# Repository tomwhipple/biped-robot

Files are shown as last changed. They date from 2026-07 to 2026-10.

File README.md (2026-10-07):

# Biped

A ~46 cm (to the deck; 56 cm to the top of the head) 3D-printed **bipedal
robot**: 17 serial-bus servos — six per leg, a neck, and two 2-DOF arms that
push it back up after a fall — an ESP32 running the 50 Hz control loop, and a
Raspberry Pi with a head camera. It is designed to walk by lifting a foot
clear of the ground: a static single-foot stance exists with 30 mm of margin,
and the first walk is an open-loop gait validated in simulation against the
measured actuation chain; a reinforcement-learning policy comes after the
body has proven its margins on the floor.

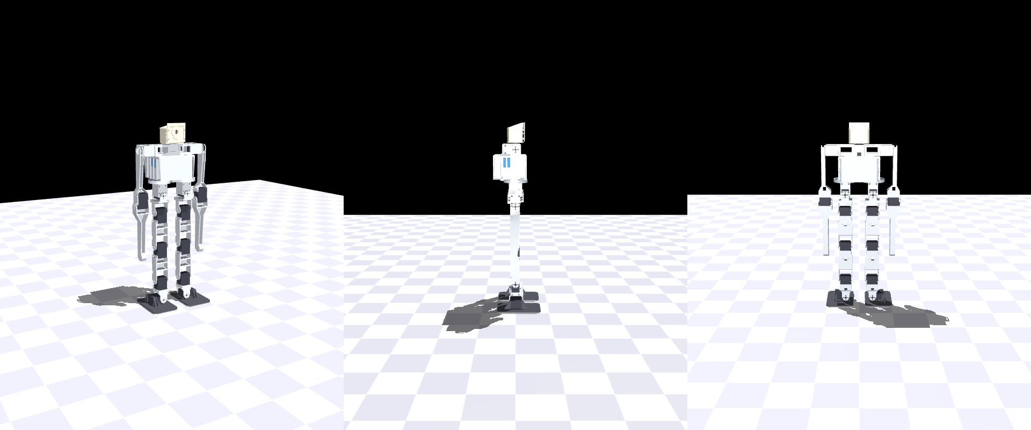
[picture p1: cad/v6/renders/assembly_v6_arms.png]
The robot as drawn: front 3/4, side, front


**Status:** designed, not yet built. The CAD is complete and passes its
swept-ROM interference gate; the design passes simulation Gates A–D. The next
step is one bench measurement on one servo — whether raising the STS3215's
position-loop gain gives the roll-joint stiffness the walk needs (issue #73) —
which gates the servo purchase and the first print. The software stack
(firmware, command link, training, software-in-the-loop) runs on hardware today
on a 10-joint prototype and is being ported to the 17-joint robot.
Where everything stands: [DESIGN.md](DESIGN.md) §12–13 and the GitHub issues.

*Loosely inspired by the [Bimo Project](https://github.com/mekion/the-bimo-project);
an independent design built from servo datasheet dimensions, not reverse-engineered
parts.*

## Try it

Everything below runs on a laptop with no robot and no GPU.

```bash
python -m venv .venv && source .venv/bin/activate    # direnv does this via .envrc
pip install -r requirements.txt

# look at the robot: drag its joints under gravity, push it over (native Qt window)
python sim/joint_puppet.py                 # standing; --pose supine | prone
python -m mujoco.viewer --mjcf=sim/bimo_biped_v6ar.xml

# the design gates, on the robot's plant
MUJOCO_GL=cgl python sim/static_gait.py --render sim/renders/walk.mp4   # the open-loop walk
python sim/gate_no3250.py walk             # the walk across the gate cases

# regenerate the printable parts from the parametric source, then gate them
ARMS=1 python cad/v6/parts_v6.py           # STLs + STEPs + rollup, with the arms
sh cad/run_checks.sh                       # swept-ROM interference, must PASS

# the test gates (also run by the pre-push hook)
python -m pytest tests/ -q                 # ~4 min: physics parity, protocol, ROM, referee, design gates
make -C firmware/host check                # the firmware's pure modules under ASan/UBSan + the consoles
```

The console drives a simulated robot over the real command protocol, and
`--host <robot-ip>` drives a real one:

```bash
brew install glfw && make -C firmware/host deps gui
firmware/host/build/bimo_gui --host 127.0.0.1
#   SIM: pick a run, Start; [a] arm, arrows to walk, PgUp/PgDn to turn
```

**Trained policies are not in the repo.** They are local artifacts under
`sim/runs/` (gitignored); [docs/training.md](docs/training.md) walks the pipeline
from the physics model to the weights compiled into the firmware. Training
wants an NVIDIA GPU; the referee, distillation and export run on a laptop.

## Where to read next

| | |
|---|---|
| [DESIGN.md](DESIGN.md) | **the design**: requirements, kinematics, servos, body, get-up, validation, open decisions, build sequence |
| [cad/README.md](cad/README.md) · [cad/PRINT_LIST.md](cad/PRINT_LIST.md) | the parametric CAD, and what to print and how |
| [docs/bom.md](docs/bom.md) · [docs/assembly.md](docs/assembly.md) | what to buy, and how to put it together |
| [docs/wiring.md](docs/wiring.md) · [docs/servo-map.md](docs/servo-map.md) · [docs/bringup.md](docs/bringup.md) | power and electrical, servo IDs and calibration, bare board to first arm |
| [firmware/README.md](firmware/README.md) · [docs/firmware-design.md](docs/firmware-design.md) | what runs on the ESP32 |
| [docs/control-channel.md](docs/control-channel.md) | the wireless command protocol and its failsafe |
| [docs/training.md](docs/training.md) · [docs/sil-harness.md](docs/sil-harness.md) | how a policy is trained, refereed and deployed |
| [AGENTS.md](AGENTS.md) | working practices: gates, branching, generated files, bench safety |
| [docs/design-v6/](docs/design-v6/README.md) | dated design records and the evidence behind DESIGN.md's numbers |
| [docs/archive/](docs/archive/README.md) | the project's history: the prototype, lessons learned, earlier studies |

## What's in here

```
cad/v6/     the robot's parametric CAD (build123d); cad/v6/dimensions_v6.py is the source of truth
cad/        shared CAD builders and checks, and the prototype's parts (its plant still trains)
sim/        the plants, design gates, open-loop gait and get-up; the CPU env (referee); sim/mjx/ (GPU training); sim/sil/
firmware/   the ESP32 target: the 50 Hz control loop, and its host test build
link/       the command channel: wire protocol, consoles, bench probes
tools/      sim <-> firmware exporters, and instruments that measure servos and the IMU
infra/      nightly training on the GPU box, burst compute
docs/       build, electrical, software and design records
```

## Hardware

17 × Feetech STS3215 (12 V) · Waveshare General Driver for Robots (ESP32,
onboard IMU) · Raspberry Pi 4B + Camera Module 3 Wide · 3S 2200–2600 mAh LiPo ·
PETG prints + silicone rubber soles. Full list: [docs/bom.md](docs/bom.md).

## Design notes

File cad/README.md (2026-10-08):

# CAD

The robot's parametric CAD, written in Python with
[build123d](https://build123d.readthedocs.io/). It lives in **`cad/v6/`**.

- **Dimensions:** every dimension comes from `cad/v6/dimensions_v6.py`. That file
  takes every servo-interface number from `cad/dimensions.py`, which is measured
  from the servo vendor's STEP model.
- **Related docs:** the design is [DESIGN.md §5](../DESIGN.md); what to print and
  how is [PRINT_LIST.md](PRINT_LIST.md); assembly is
  [docs/assembly.md](../docs/assembly.md).

```
cad/
├── v6/                     the robot: part modules, assembly, gates (map below)
│   ├── stl/  step/         exported parts and assemblies (generated)
│   └── renders/            part renders, assembly views, fly-in filmstrips
├── dimensions.py           servo ground truth and shared constants
├── parts.py                shared solid helpers; the prototype's part builders
├── check_assembly.py       servo mocks (used by cad/v6); the prototype's interference check
├── check_printability.py   the printability audit engine
├── fasteners.py            screws as solids (prototype); the hip interfaces' screw sets
├── run_checks.sh           the CAD gate
├── slice.py, orca_profile.py        OrcaSlicer CLI wrapper (PRINT_LIST.md, Slicing)
├── render_part.py, render_assembly.py, animate_assembly.py   renders (below)
├── vendor/ST3215.step      the servo's vendor STEP
└── stl/  step/  renders/   the prototype's parts and renders
```

The prototype's part builders in `parts.py`, and its `cad/stl` and `cad/step`,
exist because the 10-joint training plant (`sim/bimo_biped_v5body.xml`) meshes
`cad/stl`.

## `cad/v6` module map

| module | what it is |
|---|---|
| `dimensions_v6.py` | every dimension the robot adds or changes: kinematics, feet, torso, pack, Pi, neck and head, the hip-yaw bearing (`YAW_BRG_*`, a 6810-2RS), arms and girdle. It re-exports `cad/dimensions.py` as `D`, and `SIM_EXPECT` is the set of numbers the plant must share (pinned by `tests/test_v6_design_gates.py`) |
| `parts_v6.py` | exports every printed part to `stl/` and `step/`, with a bed check and the mass rollup `docs/design-v6/parts_v6_rollup.txt` (`--only <names>`, `--no-export` for the rollup alone) |
| `assembly_v6.py` | the articulated robot: one kinematic chain of parts, servo mocks and electronics mocks, posable (`--pose knee=-60,...`). Writes `step/assembly_v6_arms.step` (`assembly_v6.step` with `ARMS=0`) and `renders/assembly_v6_arms.png`. The checker, the fly-in and the step figures read this chain |
| `check_assembly_v6.py` | the CAD gate: every pair of pieces that move relative to each other, at the ROM extremes plus interior samples; the relatively fixed pairs that must keep their distance (`--joint static`); every disc screw's thread engagement (`--joint screws`). Options: `--joint`, `--samples`, `--side` |
| `animate_v6.py` | fly-in along each part's insertion path. Writes `renders/assembly_v6_flyin*.mp4` (gitignored) and a committed `_strip.png` |
| `render_steps_v6.py` | the assembly guide's step figures, `docs/assembly/v6_*.png`: bench order, the incoming part orange along its insertion path |
| `pelvis_v7.py` | the torso, one print: `pelvis_v7(arm_mounts)` with the yaw servos' seats and the bearing housing's five pilot bosses, its `SCREWS()`, a driver-access check and the board slide checks |
| `yaw_bearing_housing.py` | the hip-yaw bearings' outer-race seats for both hips, one print screwed up under the pelvis, and its `SCREWS()` |
| `yaw_carrier_v6.py` | the prototype's carrier with a 5 mm spacer under its horn plate (`YAW_CARRIER_DROP`: the roll servo and its screws sit below the bearing band) and a round hub for the 6810-2RS's inner race (trimmed below to pass the bearing), and its `SCREWS()` |
| `hip_yoke_v6.py` | the hip roll and pitch clevises fused into one print |
| `yoke_pitch_v6.py` | the pitch clevis alone. `hip_yoke_v6` is built from it; it is printed only under `HIP_YOKE_VARIANT=split` |
| `leg_link_v6.py` | thigh and shin (one part): a 110 mm open-front U with an end wall at each end of the open span |
| `ankle_link.py` | grips the ankle-pitch servo and forks onto the ankle-roll servo |
| `foot_v6.py` | `foot_L`/`foot_R` and the soles' outline `sole_tpu_L`/`_R` (cut from 2 mm silicone sheet) |
| `head.py` | `head_shell`, `head_face`, and `head` (the two fused, for checks) |
| `neck_floor.py` | the neck servo's seat: a plate screwed up into the neck tube's bosses, in the deck's battery aperture (#90); its checks and `tube_bosses()` |
| `neck_collar.py` | the `ARMS=0` variant's neck tube (not a print target: its flange pilots miss the deck) |
| `shoulder_girdle_v6.py` | the girdle: both shoulder pods and the neck tube in one print |
| `arm_v6.py` | upper arm and forearm (mirror pairs), the elbow-servo mock, and the elbow ROM check |
| `audit_torso.py` | printability report for `pelvis_v7`, the head parts and `neck_collar` |
| `audit_ankle_foot.py` | printability report for `ankle_link` and `foot_L/R` |
| `audit_leg_link.py` | printability and interface audit for `leg_link_v6` |
| `check_hip_yoke_clearance.py` | clearance A/B between the hip yoke's raw union and the styled part |
| `print_settings.json` | what `cad/slice.py` slices with: the print spec over Flashforge's presets, and each part's print orientation, supports, copies and overrides. Settings saved in a part's project from the OrcaSlicer GUI are written back here ([PRINT_LIST.md](PRINT_LIST.md), Slicing) |

## Shared builders in `cad/`

- **`dimensions.py`** is the single source of servo truth. It holds:
  - the case, the horn and idler discs and their tapped flanges, the screw rows,
    the rib and platform detents, the idler face, the connector trench and the
    countersinks;
  - the walls and fits (`FIT = 0.30`), the filament density and print factor,
    and the bed size.

  Every `cad/v6` module takes these from here and never retypes them.
- **`parts.py`** provides two things:
  - the solid helpers every `cad/v6` module uses: `box`, `cyl_x/y/z`, `teardrop_x/y`,
    `wedge_x/y/z`, `csk_x/y/z`, `bcd_x`;
  - the prototype parts the robot reuses: `yaw_carrier` (inside `yaw_carrier_v6`), `yoke_roll` and `yoke_pitch` (inside `hip_yoke_v6`), and
    `leg_link` (the basis of `leg_link_v6`).

  Its `main()` exports the prototype's parts to `cad/stl` and `cad/step`.
- **`check_assembly.py`** provides `servo_mock()`: the STS3215 in one canonical
  frame, built from the vendor STEP. `servo_mock_x/_y/_z` are rotations of it,
  so the three orientations cannot drift apart. It also has the board mocks.
  The `cad/v6` assembly and part modules use these. Its `main()` is the prototype's
  own interference check, and it holds the disc-screw engagement rule
  ([docs/assembly.md §1](../docs/assembly.md#1-the-joint-the-servo-is-the-axle)).
- **`check_printability.py`** is the audit engine.
  - It rotates each STL into its print orientation and classifies down-facing
    facets as CEILING, LEDGE, ISLAND, BEAM, first-layer CONTACT or thin wall.
  - Parts listed in `SUPPORTED` are expected to need slicer supports, so their
    overhang findings are reported as support needs, not failures.
  - The v6 audits point its `STL` directory and `ORIENT` table at `cad/v6` at
    runtime.
- **`fasteners.py`** models the prototype's screws as solids. The robot's fastener
  counts take the hip interfaces from it:
  - `disc_screws_x` / `disc_screws_y`, for the hip yoke's roll and pitch
    clevises;
  - `yaw_horn_screws` + `yaw_wall_screws`, for the carrier.

## Regenerate

```bash
.venv/bin/python cad/v6/parts_v6.py                      # the robot: every printed part -> cad/v6/stl + cad/v6/step, bed check, rollup
.venv/bin/python cad/v6/parts_v6.py --no-export          # the rollup alone
.venv/bin/python cad/v6/head.py                          # head_shell, head_face (+ the fused head), audits, render
.venv/bin/python cad/v6/assembly_v6.py                   # step/assembly_v6_arms.step + renders/assembly_v6_arms.png
.venv/bin/python cad/v6/assembly_v6.py --pose hip_pitch=-60,knee=90 --step /tmp/posed.step --png /tmp/posed.png
.venv/bin/python cad/v6/animate_v6.py                    # fly-in mp4 (gitignored) + filmstrip
.venv/bin/python cad/v6/render_steps_v6.py               # docs/assembly/v6_*.png
.venv/bin/python cad/v6/<module>.py                      # one part: STL + STEP + its own audits + render
.venv/bin/python sim/build_v6_inertia.py --write         # the plant from the exported STLs (sim/bimo_biped_v6ar.xml)
.venv/bin/python cad/parts.py                            # the prototype's parts -> cad/stl, cad/step (the training plant meshes them)
```

- **Each part module's `__main__`** exports that part and runs its own audits.
- **Renders on the Mac need `MUJOCO_GL=cgl`.** The scripts default it to `egl`
  (Linux), and on macOS they then skip the render.
- **The exports are generated files:** regenerate them, never edit them. See
  [AGENTS.md](../AGENTS.md). The `ARMS=0` pelvis exports as
  `pelvis_v7_armless`, so it never overwrites the robot's `pelvis_v7`.

**Environment flags** (the defaults are the robot to print):

| flag | default | read by | effect |
|---|---|---|---|
| `ARMS` | `1` | `parts_v6.py`, `assembly_v6.py` (and so `check_assembly_v6.py`, `animate_v6.py`, `render_steps_v6.py`) | the girdle, the four arm links, and the pelvis with the ten girdle pilots. `0` is the armless variant: `neck_collar`, no pilots, no arms |
| `HIP_YOKE_VARIANT` | `single` | `parts_v6.py`, `assembly_v6.py` | `split` builds the bolted `yoke_roll` + `yoke_pitch_v6` pair instead of `hip_yoke_v6` |
| `SERVO_PLAN` | `hips` | `parts_v6.py` (`sim/build_v6_inertia.py --servo-plan`) | `hips`: STS3250s at the two hip rolls, STS3215s elsewhere; `B`: 17 × STS3215; `3250`: STS3250s at the six roll and knee joints (masses only; same case) |
| `MUJOCO_GL` | `egl` (set by default) | every render | set `cgl` on macOS |

## The gate

```bash
sh cad/run_checks.sh          # exit 0 = clear; "CHECKS FAILED -- do not print" otherwise
```

It runs four things with `.venv/bin/python`:

1. **`check_assembly_v6.py` on the default build (the robot, with arms).**
   Every relatively-moving pair is posed at its joint's ROM extremes and
   interior samples. The hip-yaw bearing is in the chain as its two races,
   split at SKF's ring shoulders: the turning side must clear the fixed race
   and the bearing housing through the yaw sweep, and the leg must clear both
   races and the housing.
   - Each pair must show zero intersection and at least `SWEEP_BUFFER` of
     clearance. Designed contacts (pads on discs, seats) are checked for
     volume only, by name.
   - The relatively fixed pairs (the neck floor over the pack, off the pelvis
     and the boards) are checked at the standing pose, each against its own
     minimum distance. The bearing's two press fits must overlap by exactly
     their designed interference volume.
   - The hip's bench order (`--joint insert`): each part swept up its
     insertion path into the state the earlier steps left -- yaw servo,
     carrier, roll servo, bearings into the housing, housing and bearings
     onto the hubs. Only the press fits may overlap; one KNOWN pre-existing
     defect (the seated yaw servo against the cell ceiling) is reported, not
     failed.
   - A 7 mm driver's straight path to every carrier and bearing-housing screw
     in the state that screw is driven in (`--joint access`).
   - Every disc screw's thread engagement is checked against its flange.
   - The pair list is printed with the result, because a pair that is not listed
     was never checked.
   - Results are recorded in `docs/design-v6/cad_rom_check.txt`.
2. **The same check with `ARMS=0`** (the armless variant).
3. **`audit_torso.py`**, a printability report on `cad/v6/stl`.
4. **`audit_ankle_foot.py`**, likewise.

The two printability reports do not fail the run: `pelvis_v7` and `ankle_link`
carry ceilings and islands by design, and supports are the slicer's job. Read
their `**` lines against the slice preview.

**What the gate does not cover:**

- **The other printed parts** audit themselves from their module's `__main__`
  (`leg_link_v6`, `hip_yoke_v6`, `shoulder_girdle_v6`, `arm_v6`). Those rewrite
  their STL as they run, so run them when that part changes.
- **Insertion paths:** on a layout change, `animate_v6.py` proves that the parts
  fly in along them.

`run_checks.sh` is not in the pre-push hook. Run it for any CAD change
([AGENTS.md](../AGENTS.md)).

## Viewing in FreeCAD

Open the STEP exports:

- **the robot:** `cad/v6/step/assembly_v6_arms.step` (`assembly_v6.step` is the
  armless variant);
- **each part:** `cad/v6/step/<part>.step`.

A posed robot is `assembly_v6.py --pose ... --step <file>`. Use the CAD, not
the PNGs, to judge a design: the renders are for documentation.

**Optional: the FreeCAD MCP addon** lets an agent drive a running FreeCAD.

- It is installed in FreeCAD's `v1-1/Mod` and registered user-scope with
  `uvx --with 'mcp[cli]<2' freecad-mcp`.
- It needs the FreeCAD GUI running; the addon's RPC listens on port 9875.

## Servo geometry: the ground truth

**The sources:**

- `cad/vendor/ST3215.step`, Waveshare's STEP model;
- the dimensioned drawing and the Feetech datasheet in
  `docs/datasheets/st3215/`.

`cad/dimensions.py` measures from these programmatically; nothing comes from
photos. The STS3235 and STS3250 share this case, horn and disc pattern, so a
servo swap changes no geometry.

| feature | value |
|---|---|
| case | 45.22 × 24.72 mm, 34.7 across the output axis (35 with the boss); output axis 10.11 from the output end |
| discs | metal horn and free-spinning idler, both Ø19.2 with 4 × M3 on Ø14, tapped through a 2.5 mm (horn) and 2.1 mm (idler) flange |
| case holes | M2.5 at rows 8.30 / 29.00 behind the axis (horn face) and 8.30 / 32.75 (idler face), ±10.25 across |
| idler face | the disc and its hub rotate and stand proud; the stator screw bosses sit 1.78 below the cover slab (mounts land on pads); a horn-side rib sits on the cable half |
| **connector trench, on the idler face** | the two bus ports side by side across the width, in a trench 11.75–16.35 mm from the axis toward the cable end, ±10.9 wide, floor 4.78 below the slab (`SV_CONN_*`) |

**Lead openings belong over the connector trench.** The ports are not on the
cable-end face.

## Renders of the prototype plant

These three scripts render the prototype's parts in `cad/stl`. The training
report (`sim/build_report.py`) reads `cad/renders/assembly_mujoco.png` and
`assembly_flyin.gif`.

| script | output |
|---|---|
| `render_part.py <name or path.stl>` | one STL as a strip of views: `cad/renders/<name>.png`. It takes any STL path, so it works on `cad/v6/stl` parts too |
| `render_assembly.py` | `cad/renders/assembly_mujoco.png` |
| `animate_assembly.py` | `cad/renders/assembly_flyin.gif` and `.mov`, both gitignored |

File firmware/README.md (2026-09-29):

# firmware/ — what runs on the ESP32

The robot's control firmware: an ESP-IDF v5.4, C++17 project for the
Waveshare **General Driver for Robots** (ESP32-D0WD-V3). It boots benched
with torque released, arms over the radio or the USB tether, and runs the
50 Hz policy loop on core 1 with the distilled network compiled into flash.

- Design and rationale: [docs/firmware-design.md](../docs/firmware-design.md)
- Wire protocol and failsafe: [docs/control-channel.md](../docs/control-channel.md)
- First power-up and calibration on the robot: [docs/bringup.md](../docs/bringup.md)
- Servo IDs and calibration values: [docs/servo-map.md](../docs/servo-map.md)
- Electrical: [docs/wiring.md](../docs/wiring.md)
- Bench safety rules: [AGENTS.md](../AGENTS.md#bench-safety)

**Two joint sets.** The **bus** is the robot's 17 servos
(`components/obs/include/obs/bus_map.h`, the proposed ID map of
[docs/servo-map.md](../docs/servo-map.md) §2.1): the calibration blob,
`main/mech_envelope.h`, `pose`/`home`, the gain check, the telemetry joint
block and the SIL arrays are all 17 wide. The **policy** is what the compiled
network observes and commands, from the generated `obs_spec.h`: the
prototype's 10 joints (`kNumJoints = 10`,
`kServoId = {10, 5, 6, 7, 8, 9, 1, 2, 3, 4}`, plant
`sim/bimo_biped_v5body.xml`), policy `loco_v41rsi_b_s128r24`. The loop drives
the policy's joints and holds every other fitted servo; the prototype's
calibration marks IDs 11–17 not fitted
([docs/firmware-design.md](../docs/firmware-design.md) §5.8).

## Build and flash

```sh
env -u VIRTUAL_ENV bash                 # export.sh will not run inside a virtualenv
. ~/esp/esp-idf/export.sh
idf.py -C firmware set-target esp32     # once, for a fresh build directory
idf.py -C firmware build
idf.py -C firmware -p /dev/cu.usbserial-XXXX flash monitor
```

- `export.sh` uses the first `python3` on `PATH`, and it must be the Python
  ESP-IDF's `install.sh` was run with. ninja is optional (`brew install
  ninja` for faster incremental builds).
- The partition table is `partitions.csv`: a 3 MB app partition, with `nvs`
  and `phy_init` at the stock offsets so a reflash keeps the calibration. The
  image is 1 012 832 B, 68 % of the app partition free.
- `sdkconfig` is gitignored and `sdkconfig.defaults` only seeds a new one. A
  checkout configured before the partition table changed is refused at
  configure time: delete `firmware/sdkconfig` and build again.
- The board enumerates as a CP2102N (`/dev/cu.usbserial-*`; macOS may need the
  [CP210x driver](https://files.waveshare.com/wiki/common/CP210x_USB_TO_UART.zip)).
  **Only the USB-C port silkscreened `USB` flashes**; the one silkscreened
  `LIDAR` enumerates a port that never syncs.
- **Opening the serial port resets the board**, which eats the first command
  sent after connecting. Drain and verify before any state-writing command.
- The board boots **benched, torque released**. Nothing moves until `run` on
  the tether or an ARM edge over the radio. Any goal-position write enables
  torque on an STS3215, so every bus write is a motion command.

The pre-push hook (`.githooks/pre-push`) also runs the target build; it finds
ESP-IDF through `idf.py` on `PATH` or `$IDF_PATH`.

## On-target bring-up

[docs/bringup.md](../docs/bringup.md) is the procedure, from a bare board to
the first arm: servo IDs, calibration, the IMU's bias, mount and scale taken
on the robot in the standing pose, WiFi and NTP, torque-release drills, then
the policy loop with the robot on a stand before the floor. `stat` reports
the tick timing and fault counters along the way.

## Host tests (the hardware-free gate)

```sh
make -C firmware/host test     # 10 suites under ASan/UBSan, plus libctrl_sil
make -C firmware/host check    # test + the bimo_tui build (+ bimo_gui on macOS)
```

`check` is what the pre-push hook runs, alongside a CMake + `ctest` build of
the same tests (`firmware/host/CMakeLists.txt`; keep it in step with the
Makefile). Everything compiled here is the same source the board runs, built
with `-Wall -Wextra -Werror -Wshadow -Wconversion -Wsign-conversion`; the
hardware-touching files are excluded by construction.

| suite | covers |
|---|---|
| `protocol` | `linkproto` against golden vectors generated from `link/protocol.py`: frames, CRC, watchdog, arm and home latches, bench diagnostic, UART demux |
| `scsbus` | packet codec against the worked examples in Feetech's protocol manual; transactions against a scripted fake port (a missing servo mid-sync-read, a reply from the wrong ID); the guarded gain write (refused with torque on or unreadable, re-locks on failure, never a goal) and the gain check |
| `obs` | the assembler against real `walker_env._obs()` frames, history order, gait clock, action/angle/tick maps, command shaper, the bus map against the policy spec, calibration blob pack/unpack and the v2 → v3 and v1 migrations |
| `policy` | the forward pass against numpy golden vectors; asserts the weights are the deployed run, not a placeholder |
| `battguard` | the pack guard's thresholds, debounce and landing ramp |
| `fusion` | the attitude filter, cross-checked against MuJoCo's `framezaxis` |
| `obsdump` | the observation dump's double buffer and CSV writer; the mirror-mode pose buffer |
| `sil` | `libctrl_sil`'s C ABI end to end: tick round trips, the bus permutation, the held bus slots, `.silw` and calibration parsing on adversarial input |
| `sil_golden` | the firmware against the sim's own numbers in `sim/sil/golden/*.json`. The obs cases always run; the policy cases run only when the golden run's `.silw` is present and are skipped otherwise |
| `client` | the console core in `link/`: intent, frame-length rule, keymap file, MJPEG parser, recorder, the servo-fault ID list |

The Python half of software-in-the-loop is [sim/sil/README.md](../sim/sil/README.md);
`pytest sim/sil` runs in the pre-push hook after `check` (it needs the library
`check` builds), against the deployed run.

Other targets:

```sh
make -C firmware/host sil       # build/libctrl_sil.{dylib,so} only
make -C firmware/host tui       # build/bimo_tui
make -C firmware/host deps gui  # build/bimo_gui (fetches pinned Dear ImGui + stb into third_party/)
make -C firmware/host vectors   # regenerate protocol_vectors.h from link/protocol.py
make -C firmware/host deploy-headers RUN=<run>   # obs_spec.h + weights.h (+ vectors) from one run
```

`obs_spec.h`, `weights.h` and the files in `host/vectors/` are generated
(AGENTS.md lists the generators); never hand-edit them. The two deployed
headers change only together, and only because somebody named the run to
deploy.

## Module map

```
firmware/
  CMakeLists.txt        ESP-IDF project; -Wall -Wextra -Werror, no exceptions/RTTI
  sdkconfig.defaults    240 MHz, dual core, 1 kHz FreeRTOS tick, static allocation,
                        1 s task watchdog, 4 MB flash / no PSRAM, SNTP settings,
                        the custom partition table
  partitions.csv        nvs + phy_init at the stock offsets, a 3 MB app partition
  main/                 everything that touches ESP-IDF
    board.h             the pinout, from the vendor schematic
    app_main.cpp        NVS, UARTs, IMU, calibration restore, torque off, start tasks
    ctrl_task.cpp       core 1, 50 Hz: sense, guard, observe, act (owns the bus when armed)
    link_task.cpp       core 0: UART0 reader (`link`) and the `housekeeping` task
    wifi_link.cpp       core 0: WiFi station, UDP commands in, telemetry beacon out
    imu_sampler.cpp     core 0: 250 Hz IMU read + fusion, tick-averaged gyro
    timesync.cpp        SNTP wall clock for telemetry timestamps
    cli.cpp             the bench CLI
    cal_store.cpp       servo and IMU calibration blobs in NVS, CRC'd
    asbuilt_cal.h       the as-built zero table (reference for blob migration)
    servo_gains.h       expected position-loop P/D per servo ID (the arm gate)
    mech_envelope.h     per-bus-joint mechanical limits for bench moves
    obs_dump.cpp        the observation dump (`obsdump`)
    joint_pose.h        measured pose, core 1 -> the beacon (mirror mode)
    scs_port_idf.cpp    scsbus::Port over UART1 -- the one servo-bus hardware seam
    shared.h            the only cross-core state, and the rules for it
  components/
    scsbus/             Feetech SCS/STS protocol: codec, transactions, registers;
                        the guarded gain write and the gain check (gains.h)
    linkproto/          C++ port of link/protocol.py: frames, Watchdog, latches, UART demux
    obs/                obs assembler, history, gait clock, actuation maps, shaper;
                        bus_map.h (the 17-servo bus); obs_spec.h (generated)
    policy/             static MLP forward pass; weights.h (generated)
    imu/                Imu interface, frame maths, Fusion, QMI8658C driver, StubImu
    battguard/          pack under-voltage guard
  host/                 host build: Makefile + CMakeLists, 10 test suites, the SIL
                        library (sil.h, sil_lib.cpp, sil_net.cpp), vectors/
tools/
  gen_protocol_vectors.py   link/protocol.py -> host/vectors/protocol_vectors.h
  gen_obs_spec.py           run config + MJCF -> obs/obs_spec.h + obs_vectors.h
  gen_policy_weights.py     <run>.silw -> policy/weights.h + policy_vectors.h
```

## The CLI

USB serial at 115200 on the `USB` port. `help` prints the list. Commands that
touch the bus work only while benched (`run` refuses them); commands that
write NVS are bench-only because a flash write stalls the control tick.

| command | does |
|---|---|
| `scan` | ping IDs 0–253; report position, voltage, faults |
| `ping [id]` | no id: every bus servo, against the fitted set |
| `id <old> <new>` | assign a servo ID (EEPROM; one servo on the bus) |
| `pos <id>` | position, speed, load, voltage, temperature, faults |
| `move <id> <ticks> [ms] [steps/s]` | one servo; 2048 = middle, 4096 ticks/rev; clamped to the mechanical envelope |
| `pose <17 ticks> [...]` / `pose <10 ticks> [...]` | 17 targets in servo-ID order (every bus servo), or 10 in policy order (the prototype's tools); unfitted servos ignored; streamed as a smooth minimum-jerk move by default |
| `trace` | dump the per-servo trace recorded during the last `pose` stream |
| `reg <id> <addr> [1\|2]` | read a servo register |
| `gains [id [P D]]` | position-loop P/D (registers 21/22): no id checks every driven servo against `main/servo_gains.h` (the arm gate); `<id>` reads one; `<id> <P> <D>` writes one, only with its torque off (EEPROM unlock, write, lock, read back; no goal) |
| `home [steps/s]` | every joint to its calibrated zero, hip play take-up, readback, torque released |
| `release [id]` / `torque [id]` | torque off / on; no id = broadcast |
| `middle <id>` | latch the current angle as the servo's 2048 (register 40 ← 128), torque off |
| `volt` | pack voltage, read off the servos |
| `batt [reset]` | pack guard state; `reset` clears a latched trip after a pack swap (bench) |
| `cal [show\|zero [j]\|dir j d\|set j z d\|fit j 0\|1\|migrate\|save\|load\|reset]` | per-bus-joint zero, direction and fitted flag in NVS; `j` is a joint name or a servo ID |
| `shape [hz]` | command-shaper pole; 0 = raw targets |
| `obsfreeze [none\|up\|gyro\|imu\|dq\|gain=k]` | pin or scale parts of the policy observation (diagnostic, not persisted) |
| `run` / `bench` | hand the bus to the control loop / take it back; `run` refuses without an NVS calibration or with any servo's gains off the expected table |
| `imu [scan\|raw [n]\|ring [ms]\|avg [on\|off]\|gscale [x y z]\|reinit\|bias\|mount\|forget\|ae]` | IMU status, I²C scan, raw axes, ringing meter, calibration |
| `wifi [<ssid> <psk>\|clear]` | link status and counters; credentials in NVS |
| `ntp` | SNTP sync state and server |
| `stat` | tick timing per phase, overruns, worst tick, IMU sampler, policy |
| `obsdump [on\|off\|once]` | stream the policy observation as CSV (armed only) |

## Known gaps, as they stand

- `vx_est`/`wz_est` are not estimated and go out as 0.
- `battguard` reads pack voltage from servo register 62 (0.1 V); the on-board
  INA219 is not read.
- The velocity observation is servo register 58; whether a finite difference
  fits better is open (reported/differenced slope 0.69 on the bench).
- The IDF task watchdog on `ctrl` reports only; the loop's own overrun check
  (> 40 ms → torque off) is the protection.
- The 17-servo bus is verified on the host only: a 17-servo `pose` on the
  bench, the robot's leg envelope rows and a policy trained on the robot's
  plant (#86) remain (docs/firmware-design.md §8).

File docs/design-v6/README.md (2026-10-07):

# Design records and evidence

The dated records behind the current design, and the raw logs and figures its
numbers come from. [DESIGN.md](../../DESIGN.md) is the current design; these
records say how each part of it was decided and measured, as of their dates.
The directory name matches the CAD's (`cad/v6/`); it is the current design,
not a version among others.

## Records

| record | what it decided or measured |
|---|---|
| [2026-09-13-design-record.md](2026-09-13-design-record.md) | the validation record: requirements, kinematics sweeps, Gates A–D, servo choice, body revisions, fall-recovery studies, and **§14 Plan B** (STS3215 everywhere with raised P). Code comments cite its sections |
| [experiments/plan-b-bench/](../../experiments/plan-b-bench/) | the Plan B bench (#73), in its own folder: `gain_bench.py`, the rig (CAD, STLs, figures) and its dated sessions -- session 1, the bench servo's registers and the unloaded P ladder; gain-write ack loss (#101) |
| [getup-decision-2026-09-17.md](getup-decision-2026-09-17.md) | the get-up decision (two elbowed arms) and **every dead end with its measured reason**, so none is retried |
| [getup-noappendage-2026-09-14.md](getup-noappendage-2026-09-14.md) | the no-appendage get-up search (kip, bear, crow, bridge, skid, bumper): negative, and the hip −90…−100° crouch finding; figures in `figs/` |
| [study-shoulder-arms.md](study-shoulder-arms.md) | the arm study behind that decision: reach threshold, elbow, mount position |
| [shoulder-girdle.md](shoulder-girdle.md) | shoulders into the torso in the hip plane; assembly order; §11 the get-up re-run on the robot as drawn |
| [arms.md](arms.md) | the arm parts in CAD, their ROM and open items |
| [elbow-servo-upper-arm-2026-10-07.md](elbow-servo-upper-arm-2026-10-07.md) | the elbow servo's case moves from the forearm to the upper arm; both arm links take the leg link's open-U section with end walls; before/after on every gate |
| [hip-yoke-single-print.md](hip-yoke-single-print.md) | the hip roll and pitch clevises as one print; hip-flexion relief to −120° |
| [failure_sweep_2026-10-07.md](failure_sweep_2026-10-07.md) | failure modes of the kinematic walk on the robot plant: 434k random walks; roll play, lift height, actuation lag and swing time decide falls and lift |
| [foot_outline_2026-10-07.md](foot_outline_2026-10-07.md) | the printed foot sat 12 mm outboard of the spec; at the spec the feet touch at 2.1° of mutual hip-roll adduction. Gate D margin vs adduction clearance at three sole placements (open, for Tom) |
| [study-yaw-bearing.md](study-yaw-bearing.md) | hip-yaw bearing options A / C / E and their checks; A selected 2026-10-06 (#75) |

Records here describe what was true on their date; where one disagrees with
DESIGN.md, DESIGN.md is current. Evidence logs for options not taken (legs-only
and tail get-ups, short arms, the split hip yoke, the first arm brackets) were
removed from the tree on 2026-09-29 and remain in git history.

## Evidence

Logs (`*.txt`, `*.json`) are the verbatim output of the scripts named in their
headers; figures (`*_strip.png`) are filmstrips of the runs. The ones DESIGN.md
leans on:

| evidence | backs |
|---|---|
| `gateA_geometry_sweep.txt`, `gateB_mixed.txt`, `gateAB_v7.txt` | kinematics and actuator envelope (Gates A, B) |
| `gateCD_sweep*.txt`, `gateD_*.txt` | the open-loop walk across the adversity matrix |
| `no3250_{walk,sweep,envelope,arms_walk,getup}.txt`, `no3250_{walk,arms_walk}_plant17.txt`, `no3250_*_elbow_upper.txt` | Plan B: every gate with STS3215s and raised P; the walk on the regenerated 17-actuator plant; the elbow-servo move against main |
| `getup_search_r6_asdrawn*.txt`, `getup_search_r5_asdrawn*.txt`, `getup_search_shoulder_*.txt`, `getup_search_girdle_*.txt`, `getup_search_hipplane_*.txt`, `getup_search_legroll*.txt` | the get-up on the as-drawn robot, the arm choice, the prone roll |
| `cad_rom_check.txt`, `girdle_check_assembly.txt`, `hip_yoke_check_single.txt`, `yaw_bearing_check*.txt`, `yaw_bearing_options_2026-09-29.txt` | the CAD interference gates; the A / C / E comparison for #75 (A selected) |
| `parts_v6_rollup.txt` | part masses and the print rollup (regenerated by `cad/v6/parts_v6.py`) |
| `deep_flexion_sweep.txt` | knee 130° / hip flexion limits |

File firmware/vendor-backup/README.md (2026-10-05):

# Vendor firmware backup

`waveshare_stock_4MB.bin` is a full 4 MB dump of the Waveshare "Servo Driver
with ESP32" flash **exactly as it shipped**, taken 2026-07-26 before our
firmware was flashed for the first time.

    sha256  5ef7db3e1ea47654016b060016979e3e4b9758780dd5bf3262e1d1ac54f6db0f
    size    4194304 bytes
    chip    ESP32-D0WD-V3 rev 3.1, MAC xx:xx:xx:xx:xx:xx

**The .bin is deliberately not in git** (4 MB binary — see `../.gitignore`).
If it is missing and the board still runs vendor firmware, retake it:

```
. ~/esp/esp-idf/export.sh
esptool.py --port /dev/cu.usbserial-0001 -b 460800 \
    read_flash 0 0x400000 firmware/vendor-backup/waveshare_stock_4MB.bin
```

## Restoring it

```
. ~/esp/esp-idf/export.sh
esptool.py --port /dev/cu.usbserial-0001 -b 460800 \
    write_flash 0 firmware/vendor-backup/waveshare_stock_4MB.bin
```

That puts the stock web UI back at `192.168.4.1` (AP `ESP32_DEV` /
`12345678`), including its ID-setting page.

## Why you would, and mostly would not

Kept as insurance for the first hardware run of our firmware, not because the
vendor image is worth returning to. It is **actively wrong for these servos**:
the board ships the **SC-series** build, which is big-endian, while the ST3215
is ST-series little-endian — so every 16-bit value it exchanges is
byte-swapped. Measured on servo 9: it reported position 772 for an actual
1027, and its "Set Servo Mode" button wrote angle limits of 5120 and 60163
instead of 20 and 1003. Only 8-bit registers (ID, mode, torque) survive the
trip intact.

See [docs/bringup.md](../../docs/bringup.md) for the full measurement.

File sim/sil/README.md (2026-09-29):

# Software-in-the-loop (SIL) harness — usage

The firmware's real control path, driven by the CPU referee plant. The
design contract (ABI, rules, pyramid, findings) is
[docs/sil-harness.md](../../docs/sil-harness.md).

```
walker_env  --calibrated ticks + IMU floats-->  libctrl_sil  --goal ticks-->  walker_env
            (SilSensors)                       (firmware code) (SilTargets)
```

Nothing in `libctrl_sil` knows it is talking to a simulator: the observation
assembler, history ring, gait clock, MLP, command shaper and angle ↔ tick
calibration are the firmware's own sources compiled for the host. This
directory is the translation layer and its tests.

## Build and run

```sh
# 1. export the deployed run (needs sim/runs/<run>/params.pkl + config.json;
#    the run is obs::kRunName in obs_spec.h). --no-golden keeps the committed
#    golden vectors in sim/sil/golden/ as they are.
JAX_PLATFORMS=cpu .venv/bin/python tools/export_policy_weights.py --run <run> --no-golden

# 2. the C side
make -C firmware/host sil          # -> firmware/host/build/libctrl_sil.{dylib,so}
make -C firmware/host test         # pyramid item 1, part of the pre-push gate

# 3. the Python side (also a pre-push gate)
.venv/bin/python -m pytest sim/sil -q                 # everything (seconds)
.venv/bin/python -m pytest sim/sil -q -m "not slow"   # skip the closed-loop scenarios
```

`conftest.py` pins JAX to the CPU. Always pass `--run` to the exporter (its
built-in default is not a run this suite uses). Without `--no-golden` it
rewrites `sim/sil/golden/*.json`, which the firmware host tests consume: do
that when the deployed run changes, in the same commit as
`make -C firmware/host deploy-headers RUN=<run>`.

Knobs (environment):

| var | default | meaning |
|---|---|---|
| `SIL_RUN` | the deployed run: `obs::kRunName`, read from `obs_spec.h` (`harness.DEFAULT_RUN`) | the run whose `sim/runs/<run>/config.json`, `params.pkl` and `weights/<run>.silw` the suite loads |
| `SIL_LIB` | search `firmware/host/build`, then `firmware/host` | explicit library path |
| `SIL_SEEDS` | `8` | closed-loop episodes per scenario; seeds are `100·i + 7`, exactly `eval_precision`'s |
| `SIL_ASSUME_ORDER` | auto-probed | force `joint` or `ascending_id` array order |

`sim/runs/` and the `.silw` blobs are gitignored. Without the run's files the
tests that need them skip, each naming the file it lacks and the command that
makes it; without the library, the library-dependent tests skip. The rest
(the one-run consistency check, the goldens, the boundary, the inverse action
map) always run.

## Current status

`pytest sim/sil` is a hard gate in the pre-push hook. On the deployed run
(`loco_v41rsi_b_s128r24`, plant `bimo_biped_v5body.xml`) it is **35 passed**
in ~15 s, closed loop included; on a clean clone, 16 passed and 19 skipped.
The headers, the goldens and the harness default are the same run, and
`test_goldens_headers_and_harness_agree_on_one_run` keeps them so
([docs/sil-harness.md](../../docs/sil-harness.md#one-run-the-deployed-one)).
The firmware MLP matches brax on the same observation to ~3e-7 (`net_err`).

## Files

| file | what it is |
|---|---|
| `tools/export_policy_weights.py` | `params.pkl` → `.silw` + sidecar (+ golden vectors unless `--no-golden`) |
| `harness.py` | ctypes ABI, calibration maths, boundary conversion, the ABI probe, `SilActAdapter`, the deployed-run default |
| `test_sil.py` | pyramid items 2, 3 and 4, and the one-run check |
| `conftest.py` | CPU-only JAX, the `slow` marker |
| `weights/<run>.silw.json` | committed sidecars; `loco_v41rsi_b_s128r24` is the deployed run's, `loco_v11gait` is `sim/sil_twin.py`'s default |
| `weights/<run>.silw` | the exported blob; gitignored, regenerated by step 1 |
| `golden/policy_vectors.json` | 16 normalised-obs → action pairs (brax, deterministic), the deployed run |
| `golden/obs_vectors.json` | 8 `walker_env` states → `_obs()` frame + `obs::Inputs`, same run |
| `cal/cal_{nominal,perturbed}.json` | the two calibrations `sil_init()` takes |

`sim/sil_twin.py` and `bimo_gui`'s SIM panel can run any run that has both
`sim/runs/<run>/config.json` and `weights/<run>.silw.json`.

## The `.silw` layout as written

Little-endian throughout. `header_bytes = 44 + 4·num_sizes` (64 for a
`147 → 512 → 256 → 128 → 20` net).

```
off  type          n           field
  0  char[4]       4           magic "SILW"
  4  u32           1           version = 1
  8  u32           1           header_bytes  (byte offset of the f32 payload)
 12  u32           1           obs_dim       (147)
 16  u32           1           act_dim       (10)
 20  u32           1           num_layers
 24  u32           1           num_sizes     (num_layers + 1)
 28  char[16]      16          activation, NUL-padded ("swish")
 44  u32           num_sizes   layer_sizes, e.g. [147, 512, 256, 128, 20]
 -- header_bytes --
     f32           obs_dim     norm_mean
     f32           obs_dim     norm_std
     f32           in_0*out_0  W0, row-major (in, out): flax order, no transpose
     f32           out_0       b0
     ...                       W1, b1, ... for every layer
```

For the 147 → 512 → 256 → 128 → 20 net the payload is 242 874 floats.
`--raw` writes the payload with no header (`header_bytes = 0`); the sidecar
is then the only description. The sidecar `<run>.silw.json` carries
`layer_sizes`, `activation`, `obs_dim`, `act_dim`, `normalizer.{mean,std}`,
the source run's plant and observation shape, and a `blob` block
(`header_bytes`, `order`, `n_floats`, `bytes`, `sha256`) so a reader can
cross-check the bytes.

What a consumer must reproduce, all in float32:

```
x      = (obs - mean) / std          brax running_statistics.normalize, no clip
h      = swish(h @ W_i + b_i)        every hidden layer
logits = h @ W_out + b_out           linear, 2 * act_dim wide
action = tanh(logits[:act_dim])      NormalTanhDistribution.mode()
```

## The calibration file

```json
{"num_joints": 10,
 "joints": [{"index": 0, "name": "L_hip_yaw", "bus_id": 10,
             "zero_steps": 2048, "dir": 1}, ...],
 "bus_id": [...], "zero_steps": [...], "dir": [...]}
```

The three flat arrays are joint-indexed mirrors of `joints`; a reader may
use either shape. `bus_id` follows the generated `kServoId`. The library
takes an entry for every servo the policy drives and accepts one for any
servo on the 17-servo bus; the harness's files carry the policy's ten.

The ctypes structs are bus-wide (17 slots, servo-ID order, `sil_abi` 3); the
harness reads the width from `firmware/components/obs/include/obs/bus_map.h`
(`harness.NUM_BUS`) and fills the slots the policy does not drive with 2048.
`cal_nominal.json` is `zero_steps = 2048, dir = +1` (identical to
`obs::Calibration`'s default); `cal_perturbed.json` has random zeros in
2048 ± 350. Neither is the as-built calibration: they describe a robot whose
servos agree with the plant, which makes them clean round-trip fixtures. The
real robot's zeros and directions are in
[docs/servo-map.md](../../docs/servo-map.md) and `firmware/main/asbuilt_cal.h`.

## The referee column (`--sil`)

```sh
cd sim/mjx && JAX_PLATFORMS=cpu ../../.venv/bin/python \
    eval_precision.py --run-name <run> --sil      # -> sim/runs/<run>/scorecard_sil.{md,json}
```

`--sil` builds the library and exports the run's weights (with `--no-golden`)
when they are missing or stale, then scores the run with the firmware stack
in the `act()` slot. `infra/night_collect_local.sh` runs it for every
collected run.

## Notes for whoever touches this next

**The ABI's array order is probed, not assumed.** `SilLib.probe()` ticks
once with a distinguishable tick pattern and reads `SilTargets.obs` back to
determine, in the tick domain (so a non-uniform calibration cannot pass for a
permutation), the sensor array order, the `goal_ticks` order, and whether
`vel_ticks` is two's complement or the servo's sign-magnitude word. It runs
with the shaper off and restores it. A disagreement is a `ProbeFailed` with
both candidate errors in the message; `SIL_ASSUME_ORDER` overrides.

**The gait clocks tick at opposite ends.** `ctrl_task.cpp` advances the clock
*before* assembling the frame; `walker_env.step()` advances it at the *end*.
So the firmware's phase at tick *k* is `(k+1)·ω` and walker_env's is
`p₀ + k·ω`. `pin_gait_clock(env, hz)` sets `p₀ = ω` (and refills the history
ring) to align them; only the per-tick parity tests need it. The closed-loop
scenarios deliberately do not pin.

**The harness takes the IMU from the observation, not from `env.data`.**
`walker_env._obs()` pushes the up-vector through a per-episode mounting
rotation, adds noise and biases the gyro, and redraws that noise on every
call. Reading those channels back out of the observation frame is the only
way to give the SIL loop the same IMU realisation the python policy saw;
reading `sensordata` would bypass the mounting error the harness exists to
exercise.

**Frozen normaliser channels.** `test_normalizer_frozen_channels_are_known`
pins which channels the suite's run never varied; see finding 2 in the design
doc for why a frozen channel the robot does feed is a hazard.

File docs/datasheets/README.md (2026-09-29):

# Datasheets

These are manufacturer documents for the parts in the build. They are mirrored
here so that CAD work and bring-up do not depend on a live listing. The owner's
policy: only source parts that have real manufacturer documentation, meaning
connector graphics and specs. A rendered web snapshot or a self-authored "manual"
does not count.

## Feetech STS3215 (ST-3215-C018): every joint

The files are in [`st3215/`](st3215/). The part to buy is the **12 V class,
ST-3215-C018** (30 kg·cm).

- The 7.4 V STS3215 shares the case but cannot run on 3S.
- Resellers (Waveshare, RCmall, Stemedu …) sell the same Feetech part, so buy by voltage class.

| file | what it is | source |
|---|---|---|
| `ST-3215-C018-datasheet-12V-30kg.pdf` | **The authoritative spec.** Ed. A/0, 2023-07-20, 8 pp. Chinese with English headings. §5 electrical, §6 mechanical, §7 control and protections, §9 outline, §10 performance curves | [feetechrc.com](https://www.feetechrc.com/525603.html) |
| `ST-3215-C018-outline-and-performance.png` | rendered quick-look of the outline and performance pages | rendered locally |
| `ST3215-outline-drawing.pdf` / `.dxf` / `.png` | standalone dimensioned drawing, 3 views plus mounting holes. The title block says "SCS215", the same case family; every dimension matches the C018 outline | Waveshare [ST3215-2D.zip](https://files.waveshare.com/upload/0/08/ST3215-2D.zip) |
| `ST3215-Servo-User-Manual-EN.pdf` | Waveshare's ST3215 user manual. It is mostly about Waveshare's Servo Driver board and its web UI, and has **no register map** | [Waveshare wiki](https://www.waveshare.com/wiki/ST3215_Servo) |
| `STS3215-datasheet-7.4V-19kg-EN-machine-translated.pdf` | The **7.4 V** part, machine-translated. Wrong voltage class. Never read torque or current from it | [Core Electronics](https://core-electronics.com.au/attachments/uploads/sts3215-smart-servo-datasheet-translated.pdf) |
| `../../cad/vendor/ST3215.step` | 3D solid, bounding box 45.22 × 37.8 × 24.72 mm | Waveshare [ST3215-3D.zip](https://files.waveshare.com/upload/5/59/ST3215-3D.zip) |

The C018's key numbers:

- 12 V rated, 4–14 V input range (protection trips outside that range).
- 30 kg·cm stall (2.94 N·m) at 2.7 A.
- 180 mA running with no load; 30 mA idle.
- 0.222 s/60° with no load.
- Backlash ≤ 0.5°; gear ratio 1:345.
- 55 ± 1 g.
- 25T output spline, OD 5.9; M3×6 horn screw.
- 5264-3P connector (1 GND, 2 V+, 3 signal) on a 150 mm lead.
- Bus at 38.4 kbps–1 Mbps; factory default 1 Mbps, ID 1.

The Waveshare wiki gives the supply as 6–12.6 V.

The drawing's dimensions, in mm:

- Case: 45.22 × 24.72; 35 overall across the output axis.
- Horn face to idler-disc face: **37.25**.
- Output axis: 10.11 from the output end, centred across the width.
- Horn and idler discs: Ø19.2, on a Ø14 4 × M3 bolt circle.
- Case bosses: ±10.25 across the width, in rows 8.30 and 29.00 behind the output axis.

`cad/dimensions.py` states the same numbers. The drawing is the receipt for them.

## Waveshare General Driver for Robots: the controller

The files are in [`general-driver/`](general-driver/), which has its own
[index](general-driver/README.md). The set is:

- the schematic;
- the dimension drawing;
- the annotated connector photo;
- the JST XH datasheet;
- the QMI8658C IMU datasheet.

## Not mirrored yet

| document | source | why |
|---|---|---|
| Feetech ST3215 memory table v3.7 (register map, defaults) | [xls](https://files.waveshare.com/upload/2/27/ST3215%20memory%20register%20map-EN.xls), cited in `firmware/components/scsbus/include/scsbus/registers.h` | the register reference behind [servo-map.md §4](../servo-map.md#4-registers) |
| Feetech communication protocol manual | [pdf](https://files.waveshare.com/upload/2/27/Communication_Protocol_User_Manual-EN(191218-0923).pdf) | packet format; the source of the `scsbus` golden packets |

## To download

These parts are in the build, but their manufacturer documents are not in the
repo yet:

| part | manufacturer documents |
|---|---|
| Raspberry Pi 4 Model B | [product brief](https://datasheets.raspberrypi.com/rpi4/raspberry-pi-4-product-brief.pdf), [datasheet](https://datasheets.raspberrypi.com/rpi4/raspberry-pi-4-datasheet.pdf), [mechanical drawing](https://datasheets.raspberrypi.com/rpi4/raspberry-pi-4-mechanical-drawing.pdf) |
| Raspberry Pi Camera Module 3 (Wide) | [product brief](https://datasheets.raspberrypi.com/camera/camera-module-3-product-brief.pdf) |
| Pololu D24V50F5, 5 V / 5 A buck | [product page](https://www.pololu.com/product/2851), with its dimension diagram. The pelvis bosses wait on the hole pattern |
| 3S LiPo pack | the chosen pack's manufacturer spec sheet: dimensions, capacity, C rating, connector |
| 3S protection board | the chosen board's manufacturer datasheet: continuous current, cut-off voltages, balance-lead pinout |

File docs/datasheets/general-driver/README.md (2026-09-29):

# General Driver for Robots: manufacturer documents

These are Waveshare's documents for the robot's controller board, mirrored
verbatim, plus the datasheets for two parts on it. Waveshare publishes **no user
manual** for this board. The connector table, the FAQ and the demo code exist only
on the wiki. Its stable permalink is
<https://www.waveshare.com/w/index.php?title=General_Driver_for_Robots&oldid=103968>,
retrieved 2026-08-03.

| file | what it is | source |
|---|---|---|
| [General_Driver_for_Robots-schematic.pdf](General_Driver_for_Robots-schematic.pdf) | the full schematic, one A3 sheet. It is the authority for every net and GPIO | [files.waveshare.com](https://files.waveshare.com/upload/3/37/General_Driver_for_Robots.pdf) |
| [General_Driver_for_Robots-dimensions.pdf](General_Driver_for_Robots-dimensions.pdf) | dimension drawing: outline **65.01 × 56.01 mm**, holes on a 58 × 49 mm grid (58 along the 65 edge) | Waveshare |
| [General_Driver_for_Robots-connector-diagram.jpg](General_Driver_for_Robots-connector-diagram.jpg) | the official annotated photo, with every connector numbered 1–27, front and back | Waveshare wiki |
| [JST-XH-connector-datasheet.pdf](JST-XH-connector-datasheet.pdf) | JST XH series, the family of the power inlet: 3 A AC/DC per contact at AWG #22, conductors AWG #30–#22 | [jst-mfg.com](https://www.jst-mfg.com/product/pdf/eng/eXH.pdf) |
| [QMI8658C-datasheet.pdf](QMI8658C-datasheet.pdf) | QST QMI8658C 6-axis IMU, the robot's IMU at 0x6B. Rev 0.6, 2021-01-13, stamped "advance information" | QST, via Waveshare |

Where the documents disagree:

- **Dimensions.** The wiki lists the board as "65 x 65mm". The drawing says 65.01 × 56.01. Trust the drawing.
- **Input voltage.**
  - The wiki says "DC 7-13V" and that the XH port "directly powers the serial bus servo and motor".
  - The rev 1.2 silkscreen says "DC 9-12.6V", which would exclude 2S.
  - This is unresolved. A 3S pack is inside both ranges.
- **Bus current.** The wiki FAQ limits bus-servo current to "5A for long-term operation", which is "up to 5 servos (ensuring that these 5 servos are not stalled simultaneously)". The robot runs 17. That is open; see [wiring.md](../../wiring.md#current-the-open-constraint).
- **QMI8658C output registers.** The datasheet's Motion-on-Demand text cites output registers 0x25–0x3D, while its dQ/dV register map puts them at 0x49–0x56. Trust the silicon, not the sheet (`imu ae` on the CLI).

The connector → net → GPIO map derived from the schematic is in
[sensor-expansion.md §1](../../sensor-expansion.md#1-the-boards-connectors). What the
INA219 measures is in [wiring.md](../../wiring.md#what-the-ina219-measures).

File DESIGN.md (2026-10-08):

# Design

The current design of the robot: what it is, why each choice was made, what
has been validated and how, and what is still open. Dated records and the
evidence behind these numbers are in [docs/design-v6/](docs/design-v6/README.md);
the project's earlier history is in [docs/archive/](docs/archive/README.md).

**State:** the CAD is complete and passes its swept-ROM interference gate
(armless and with arms); the design passes simulation Gates A–D under the
servo plan below. Nothing has been printed or bought. The first step is a bench
measurement on one servo (issue #73), which gates the servo purchase.

The robot as drawn (front 3/4, side, front)

## 1. Goal and requirements

A small 3D-printed biped that **walks by lifting one foot completely off the
ground**, gets itself up after a fall, and carries an onboard computer and a
head camera for navigation. Walking and get-up come from the body and an
open-loop gait first; a learned policy comes last, once the hardware has shown
its margins.

Each requirement traces to a measurement on the earlier 10-joint prototype
(see [lessons learned](docs/archive/2026-09-13-lessons-learned-walking.md)):

| | requirement | how the design meets it |
|---|---|---|
| R1 | A **static single-foot stance** must exist, with margin | ankle roll: a 6th joint per leg (Gate A: 30 mm CoM margin on one foot) |
| R2 | Margins are measured on the body **before any policy** | Gates A–D in simulation, then the same open-loop script on the bench; the policy (Gate E) is last |
| R3 | The **roll chains must be stiff** | every roll joint double-supported (horn + idler); servo stiffness is the one gated assumption (§4) |
| R4 | **Speed and torque margin** under load: ≥ 2× speed, ≥ 1.5× torque at 11.1 V | met at the design cadence (§8) |
| R5 | Contact realism made adversarial | every gate runs μ 0.3–1.0, full self-collision, free play on the rolls, and the deployed actuation chain |
| R6 | An onboard computer and camera | Raspberry Pi 4B in the torso, Camera Module 3 Wide in a head on a neck servo |
| R7 | Keep what is proven | hip yaw (decisive for turning in place), the "servo is the axle" leg link, one-print torso, the 50 Hz ESP32 control loop, the General Driver board, a 3S pack |
| R8 | Size may grow to ~45 cm and a bigger pack | deck top 465 mm, head top 560 mm |

## 2. The robot at a glance

| | |
|---|---|
| joints | **17**: per leg hip yaw, hip roll, hip pitch, knee, ankle pitch, ankle roll (12); neck yaw (1); per arm shoulder pitch, elbow (4) |
| servos | 15 × Feetech STS3215 (12 V, ST-3215-C018), with a raised position-loop gain on the ankle rolls and knees, and 2 × STS3250 at the hip rolls (§4) |
| height | deck top 465 mm, camera 534 mm, head top 560 mm |
| mass | ≈ 2.28 kg as drawn (§7) |
| controller | Waveshare General Driver for Robots (ESP32, onboard QMI8658C IMU), 1 Mbaud half-duplex servo bus |
| compute | Raspberry Pi 4B (vision, navigation), talking to the ESP32 |
| camera | Raspberry Pi Camera Module 3 Wide (102° HFOV) in the head, ±90° neck yaw |
| power | 3S LiPo 2200–2600 mAh (≤ 105 × 36 × 26 mm, ~170 g), protection board, inline fuse, 5 V / 5 A buck for the Pi |
| structure | PETG prints, 2 mm silicone rubber soles; M2.5 flat-head self-tappers into printed pilots, M3 screws on the servo horns and idler discs |

## 3. Kinematics

Frames: +X forward, +Y left, +Z up. Leg chain from the pelvis down: yaw → roll →
pitch → knee → ankle pitch → ankle roll.

| joint | axis | range as drawn | servo placement |
|---|---|---|---|
| hip yaw | Z | ±45° | in a cell under the pelvis's battery layer, horn down; the yaw carrier (the whole leg) bolts to the horn |
| hip roll | X | ±55° swept (sim: 30° adduction, 45° abduction) | in the yaw carrier's bay, output forward |
| hip pitch | Y | −120° … +90° | at the thigh top, 50 mm below the roll axis, gripped by the leg link |
| knee | Y | 0 … 130° flexion | at the shin top; relief cuts on the leg link allow the deep flexion the get-up needs |
| ankle pitch | Y | ±40° | hangs in the ankle link's grip channel |
| ankle roll | X | ±25° | lies across the foot, output axis fore-aft; the ankle link forks onto its horn (front) and idler (rear) |
| neck yaw | Z | ±90° | stands on the deck, horn up; the head bolts to the horn |
| shoulder pitch | Y | −90° … +200° (0 = hanging, 90 = straight back, 180 = up along the torso) | lies fore-aft inside the shoulder girdle, horn outboard |
| elbow | Y | −100° … +10° | in the upper arm's grip channel, case running up the arm; the forearm forks round it on both discs |

**Axis stack** above the sole: ankle roll 18.4 → ankle pitch 76.4 → knee 186.4 →
hip pitch 296.4 → hip roll 346.4 → hip yaw 391.5 → deck top 465.3 → shoulder
481.6 mm. Thigh and shin are 110 mm each (the same printed part); ankle pitch to
roll 58 mm; hip roll to hip yaw 45.1 mm (the yaw carrier, §5.2).

**Why these numbers** (Gate A/D sweeps, `docs/design-v6/gateA_geometry_sweep.txt`):

- **Hip separation 84 mm.** The one-foot CoM margin is half the foot width
  whatever the hips do, so the foot is the margin budget and the hips set roll
  torque: narrower is stiffer (3.4× torque margin at 70 mm, 1.0× — stalled — at
  96 mm). At 72 mm the swing foot, which sags 12–15 mm inward while it hangs,
  lands on the stance foot. 84 mm leaves 37 mm between the soles and room for
  the pack between the yaw servos.
- **Legs 110 + 110 mm.** Longer levers lower the joint rates for the same step:
  the swing knee's speed margin goes 1.1× → 1.64× from 90 to 110 mm links.
- **Feet 130 × 84 mm, sole centreline 18.5 mm outboard of the ankle-roll axis**
  (23.5 mm inboard half, 60.5 mm outboard; 75 mm toe, 55 mm heel). The open-loop
  walk fails outward — the pelvis swings inward in single support and the closed
  chain throws it out at touchdown — so the sole extends outboard. The inboard
  half is as wide as the two feet allow: at the walk's 3° mutual hip-roll
  adduction they clear each other by 2.7 mm. 4 mm PETG plate, 2 mm silicone
  rubber sole bonded flat; mirrored left/right.
- **Forward knee.** A backward knee is the forward knee with time reversed in
  the sagittal plane; it gains nothing here and needs ±55° of ankle pitch.
- **Hip yaw on every leg.** It is what makes turning work (the walk turns up to
  20° per step, §8).

## 4. Actuation: STS3215s, with an STS3250 at each hip roll

Fifteen joints are STS3215s. The two **hip rolls are STS3250s**: same case,
horn and screw rows, +19.5 g, and ≈ 4× the STS3215's stiffness in the model.
The walk and get-up are limited by **roll-chain compliance, not torque or
speed**: under single-support load a soft hip or ankle roll sags, the pelvis
drifts toward the swing side, and the closed chain springs it outward at
touchdown. With stock STS3215s at the rolls and knees the design walks 0/4
gate cases and gets up 0/12 (`docs/design-v6/no3250_*.txt`). Nothing that
leaves joint stiffness alone moves that — cadence, lift, CoM aim, landing
offsets, a lighter torso or shorter legs.

**The plan: STS3250s at the hip rolls, and a raised position-loop P
(register 21, default 32) on the ankle-roll and knee STS3215s.** The bench
(#73, [experiments/plan-b-bench/](experiments/plan-b-bench/README.md)) found
P 96 / D 0 the smoothest high-gain setting at walking speeds, at ≈ 2.8× the
stock stiffness; P 128 (≈ 3.5×) shakes more, and P 160 (≈ 4.8×) limit-cycles
under a rigid inertia. With the tuned STS3215s at 2.8×, the extra stiffness
matters at the hip rolls, and two STS3250s there match the six-STS3250
assignment (design record §14.4a; on the robot's plant with the arms,
`docs/design-v6/no3250_mixsweep28_arms_bearingA.txt` and
`no3250_mixsweep28rolls_arms_bearingA.txt`):

| servo set (the other rolls and knees: STS3215 at 2.8×) | adversity matrix (18 cases × 3 seeds) |
|---|---|
| 6 STS3250, rolls + knees | 17/18 |
| no STS3250 | 14/18 |
| 2 STS3250 at the knees | 14/18 |
| 2 STS3250 at the ankle rolls | 13/18 |
| **2 STS3250 at the hip rolls** | **18/18** (17/18 on the 74.5 g plant) |
| 4 STS3250 at all four rolls | 17/18 |

The plant builder gives the sweep one servo mass for all six roll and knee
places, so a mixed set runs on the 55 g plant and is bracketed by the 74.5 g
one. The model does not represent the bench's sweep roughness at P ≥ 96.

**What raising P buys, in the model.** The walk loads (≤ 1.2 N·m, under 45 %
of stall) sit in the servo's linear region, so P raises static stiffness
roughly in proportion. At P × 4 on rolls and knees, above what the bench could
hold smoothly, the STS3215 matches the STS3250 case for case:

| | walk, CAD plant (4 cases) | adversity matrix (18 × 3 seeds) | walk with arms (5 cases) | get-up, as drawn |
|---|---|---|---|---|
| stock STS3215 | 0/4 | 0/18 | 0/5 | 0/12 |
| **P × 4, rolls + knees** | **4/4**, CoM margin 7.5–12.2 mm, clearance 15–20 mm | **15/18** | **4/5** | **robust 6/6** |
| P × 3, rolls + knees, ≤ 1° roll play | 4/4, margin 14.1–14.7 mm | — | — | — |
| STS3250 at rolls + knees | 4/4 | 15/18 | 5/5 | robust 6/6 |

Envelope under P × 4 at the design cadence: torque margins 2.7× (hip roll),
3.2× (knee), 2.3× (ankle roll); speed 6.0×, 2.3×, 2.2×. The STS3215 knee is
under the 2× speed rule at a 1.2 s swing (1.7×), so **the gait keeps a ≥ 1.6 s
swing**. Torque is not what binds: "servos −30 %" still passes.

**Still to measure:** the STS3250's ≈ 4× is a third-party figure that the
model adopts. The two on order go on the #73 rig first, for a direct comparison
with the STS3215 data, and the per-ID P/D table follows from that. If they fall
short, the fallbacks in order are the I term (register 23), one STS3235 (same
case, metal gears) to see whether the gears are what is soft, the ST-3025
(brushless, different case: a CAD redo), and last a Dynamixel XC430 (new bus
and board). Verified STS3250 sources and its Model_Number (2825) are in
[docs/bom.md](docs/bom.md).

The gain is a register, so it can silently revert: a factory reset or a
swapped spare comes back at 32 and the robot falls at its first crossover. The
firmware reads registers 21/22 at boot and before every arm and refuses to arm
on a mismatch with its per-ID table, which is recorded in
[docs/servo-map.md](docs/servo-map.md) §4 (factory values until the bench sets
them).

**Deploy servo model** used by every gate: kp 12 N·m/rad fitted to the
STS3215 (the bench measured ≈ 17), a torque–speed clamp at 11.1 V, the
bench-measured actuation response as a 2 Hz lag plus 80 ms dead time (the
firmware's 10 Hz command shaper and the servo's own response), integer goal
ticks, 5 ms bus latency, 1° gear backlash and 3° of free play on the four roll
joints. P × N is modelled as N × the fitted stiffness on the same envelope.
Measured STS3215 facts: no-load speed 4.04 rad/s at 12 V (14 % under the
datasheet), stall ≈ 2.94 N·m, dead time ≈ 85 ms plus a first-order lag.

**The shoulder** is the most heavily loaded servo in the get-up: 1.77 N·m (65 %
of stall) on the recommended sequence. STS overload protection drops a servo to
20 % torque after > 80 % of stall for 2 s (registers 34–36), so the margin is
real but not large; the bench should confirm it.

## 5. The body

All parts are parametric build123d under `cad/v6/`, driven by
`cad/v6/dimensions_v6.py`, which takes every servo-interface number (case,
discs, screw rows, idler face, countersinks, fits) from `cad/dimensions.py` —
measured from the vendor's STEP model (`cad/vendor/ST3215.step`). Print list:
[cad/PRINT_LIST.md](cad/PRINT_LIST.md); code map: [cad/README.md](cad/README.md).

### 5.1 Legs

- **`leg_link_v6`** (×4, thigh = shin): the servo is the axle — a grip channel
  holds one servo's case, and a fork at the other end straddles the next
  servo's horn and idler discs. 110 mm, an open-front U (back web, two side
  walls) with a wall between the sides at each end of the open span against
  twist; it prints on its back. Relief cuts for 130° of knee flexion and for
  −120° of hip flexion.
- **`ankle_link`** (×2): grips the ankle-pitch servo with the leg link's grip
  plates and forks fore/aft onto the ankle-roll servo's discs. The grip is a
  box around the servo's base: the back web, both plates, and the front tine
  carried up across the full width as the front wall, on a floor the rear
  tine hangs from. The plates cannot reach straight down: beside the servo
  the rolling ankle-roll servo leaves no room under them. It prints on its
  back, with supports.
- **`foot_L` / `foot_R`**: the roll servo lies across the foot plate in a
  cradle with two screwed retention tabs; the sole (`sole_tpu_L/R`, the
  outline) is 2 mm silicone rubber, cut, for edge compliance and grip. A tab
  is a thin plate standing 26 mm off the plate, and printed sole-down it
  bends across its own layer lines at the root, so each one is braced by two
  buttress fins on its outer face, one at each end, with the screws driven
  between them (a 7 mm driver channel); the inboard fins stay inside the
  tab's width, where the ankle link is cut clear of the tab at full roll. The
  rear tab's inboard top corner is chamfered out of the rear tine's sweep. The
  tabs hold the case only at its far hole rows, so a short boss on each case
  face also takes the low hole of the row nearest the output end (one M2.5
  each, six per foot), kept off the discs and the rear tine's pad by an arc
  about the roll axis.

### 5.2 Hip

- **Hip-yaw servos** (×2) stand in their cells horn down, **built without the
  idler disc**: nothing rides their idler side, which seats flat on the cell
  ceiling (§5.3). The disc stays in the bag as a spare.
- **Yaw carrier** (×2): hangs from the yaw servo's horn and carries the hip-roll
  servo in its bay. It is the prototype's carrier with a 5 mm spacer between
  its horn plate and the bay (roll axis 45.1 mm below the horn face), so the
  roll servo and all eight of its wall screws sit below the bearing band:
  every screw has a clear driver path with the hip fully assembled.
- **Hip-yaw bearing: a 6810-2RS** (50 × 65 × 7 mm, sealed deep-groove,
  about 53 g) per hip. Without it the yaw servo's horn and four M3 screws would
  be the only connection between a 0.34 m leg and the pelvis (single-support
  thrust ~15 N, roll moment ~0.65 N·m). The bearing moves thrust and moment
  into the pelvis and leaves the servo shaft carrying torque only.
  - The inner race sits on a round hub on the carrier (Ø50.08, +0.08 mm). The
    outer race sits in a recess (Ø64.96, −0.04 mm) in the **bearing housing**
    (`yaw_bearing_housing`), against a shoulder that takes the thrust. Both
    seats get retaining compound: the fits are inside the printer's error band.
  - **The housing** is one print for both hips: two skirts joined by a bridge,
    and a rear bar, screwed up under the pelvis's cell block with five
    M2.5 × 8 (four through the rear bar, one through the bridge into the cell
    block's front web). It is not part of the pelvis print because the yaw
    servo goes up into its cell through the space it occupies (the servo's
    cable end reaches 35.1 mm from the yaw axis, past the Ø62.6 shoulder). It
    goes on last, with both bearings pressed into it, sliding onto the hubs
    from below after the roll servos are screwed in (docs/assembly.md §7).
  - The bearing band is the top 7 mm of the carrier. The hub wraps the bay
    walls' footprint, and the bore is the smallest class that leaves a 1.5 mm
    wall around the bay's open interior (the horn screws are driven up through
    it). Below the hub the carrier is trimmed to r 24.8, under the 25 mm bore.
  - The bearings are generic 6810-2RS, measured on arrival; the CAD carries
    SKF's published 61810-2RS1 ring dimensions until then. The housing's
    shoulder bears on the outer ring face between D2 (61.8, the seal) and
    Da max (63).
  - Load margin > 100×. Selection, alternatives (a 6811-2RS wrapping the
    rectangular carrier; screwed race retention) and checks:
    [study-yaw-bearing.md](docs/design-v6/study-yaw-bearing.md) (option A,
    #75).
- **`hip_yoke_v6`** (×2): the hip-roll clevis and hip-pitch clevis fused into
  one print, straddling the roll servo's discs and the pitch servo's discs. No
  flange bolts or inserts.

### 5.3 Torso

**`pelvis_v7`**, one print, deck-top-down (174 g; the bearing housing, §5.2, screws under it):

- two yaw cells at y = ±42 mm. Each yaw servo seats with its idler-side case face
  flat on the cell's ceiling, held by four M2.5 × 5 flat-heads down through it
  into the face's mounting holes (which are flush with the face: no pads). The
  ceiling has a hole for the servo's free-hub post (2.6 mm proud, its top flush
  with the ceiling top, 1.0 mm under the pack) and a relief for its moulded
  back-cover platform (1.9 mm proud);
- a 31 mm battery layer above them: the pack lies transverse on two 1 mm
  adhesive foam pads (clear of the yaw servos' turning posts), belted with a
  15 mm hook-and-loop strap, and goes in through the deck aperture (which
  also runs under the neck servo, so the deck does not seat it: §5.5);
- the General Driver vertical on the front wall and the Pi 4B vertical on the
  aft wall, both sliding down guide channels through deck slots (16 mm of
  component depth behind the Pi: low-profile heatsink, no fan);
- a 60 × 8.4 × 25 mm pocket for the protection board and 5 V buck;
- side windows for the Pi's USB/Ethernet and the driver's service edge.

The pelvis carries ten deck pilots for the girdle. The code's `ARMS=0`
variant (no girdle, no arms, `neck_collar` for the neck) builds it without
them; that variant is kept for the CAD checks and is not a print target.

### 5.4 Arms and shoulder girdle

- **`shoulder_girdle_v6`** (one print, 77 g, 200 × 58 × 33 mm) sits on the
  deck and holds both shoulder servos in open-top pods plus the neck servo's
  tube, whose side walls carry four bosses for the neck floor (§5.5). Ten
  M2.5 × 8 flat-heads into deck pilots on two edge rails. **The pack goes in
  before the girdle**: it cannot pass the neck tube or the neck floor
  afterwards, so the neck is built into the girdle on the bench first.
- **Shoulder axis in the hip plane** (x = 0), 16 mm above the deck top, arm
  planes at y = ±103.35 mm.
- **Upper arm 160 mm, forearm 160 mm.** The 0.32 m reach is a measured
  threshold: the hand must reach the floor behind the hips at hip level; 0.30 m
  never stands.
- **Arm links** (`arm_upper_v6`, `arm_fore_v6`, mirror pairs, 28 g and 42 g):
  the leg links' section, an open-front U printed on its back, with an end wall
  across each end of the open span against twist. The upper arm is
  single-sided on the shoulder horn, its four disc screws driven through a bore
  in the outboard flange; at the elbow it grips the **elbow servo's case**, the
  leg link's grip channel turned end for end so the case runs up the arm. The
  forearm forks round the elbow servo's horn and idler discs. So the elbow
  servo turns with the upper arm, and its lead crosses only the shoulder. The
  elbow clears −118° … +60° as drawn.
- Hand: a 12 mm-radius knuckle, bare PETG.
- **Rest pose: folded** — shoulder 15° forward, elbow folded 95°, so the
  forearm points forward and 20° up (`ARM_REST` in `cad/v6/dimensions_v6.py`;
  the plant's rest pose and the training preset's held targets). The arms hold
  it whenever they are not doing something else, standing and walking
  included. There, every leg joint clears the arm through its full range by
  ≥ 8.8 mm (the CAD gate), and a walking grid (hip roll ±15°, hip pitch
  −45° … +30°, knee 0 … 70°) by ≥ 17.8 mm
  ([arm_walk_grid_2026-10-07.txt](docs/design-v6/arm_walk_grid_2026-10-07.txt)).
  - **Why forward.** With the upper arm down or back, a folded forearm sits at
    the hip yoke's height, and rolling a leg outward past about 30° drives the
    yoke, the hip-pitch servo and the thigh into it. Raising the elbow forward
    lifts it out of their reach; 15° is the smallest lean with the full margin.
  - **Cost.** The arms' mass moves forward about 69 mm each, about 7 mm on the
    robot's CoM.
  - **Hanging straight** (torque off) the forearms touch the swinging legs.

### 5.5 Neck and head

The neck STS3215 stands on its idler face in the girdle's neck tube, horn up,
±90° yaw. The deck cannot seat it (its battery aperture runs under the whole
servo), so its seat is **`neck_floor`**: a 2 mm plate, its own print (4 g),
screwed up into four bosses on the tube's side walls with M2.5 × 8
flat-heads, dropping into the aperture with its top 3 mm below the deck top.
Four pads rise from it to the case's idler face, trimmed clear of the turning
idler disc and hub and of the moulded back-cover platform, and take the four
stator screws (M2.5 × 8 up through the floor, 4 mm of bite). The plate sits
4.0 mm over the pack, so the neck goes in on the bench: plate into the tube,
servo down onto the pads (leads plugged first, out through a window in the
floor under the connector trench), stator screws from below; then the girdle
goes onto the deck. The head (`head_shell` +
`head_face`, ~35 g) bolts to its horn with 4 × M3 and carries the Camera
Module 3 Wide on M2 bosses; the ribbon runs through a slot beside the axis.
A stereo alternative from one camera and four mirrors is proposed in PR #71
(not merged).

## 6. Electronics and power

Detail: [docs/wiring.md](docs/wiring.md), [docs/sensor-expansion.md](docs/sensor-expansion.md).

- **One servo bus**: all 17 servos on the General Driver's 1 Mbaud half-duplex
  TTL bus. Bus timing is not expected to bind: 12 servos take ≈ 3.4 ms of the
  20 ms tick; the 17-servo figure has not been computed.
- **Current is open**: the board's servo power path is rated 5 A continuous,
  and the servos can draw more than that in transients. The fuse, the bulk
  capacitor and a current budget from simulated walk and get-up traces are
  required before the first powered floor run.
- **Power path**: pack → protection board (≥ 15 A, over-discharge cut-off) →
  10–15 A fuse → switch → board inlet; bulk capacitor (1000 µF, ≥ 25 V) at the
  board; Pololu D24V50F5-class 5 V / 5 A buck for the Pi.
- **The ESP32 runs the 50 Hz control loop** and the servo bus; the Pi does
  vision and navigation and talks to the ESP32. How the Pi gets bus voltage and
  current for a low-battery shutdown is open.

## 7. Mass

The robot as drawn, from the CAD-inertial plant
(`sim/bimo_biped_v6ar.xml`) and the rollup
(`docs/design-v6/parts_v6_rollup.txt`):

| | |
|---|---|
| robot | ≈ 2.28 kg (the plant: 2.279 kg) |
| servos | 15 × 55 g + 2 × 74.5 g = 974 g |
| printed PETG + silicone soles | ≈ 0.80 + 0.05 kg: pelvis 174 g, bearing housing 25 g, girdle 77 g, arm links 139 g, legs from the yaw carriers down ≈ 0.34 kg, head 35 g, neck floor 4 g |
| hip-yaw bearings | 106 g (2 × 6810-2RS) |
| pack / boards + wiring | 170 g / ≈ 180 g |

With STS3215s at the hip rolls too it is 39 g lighter, and with STS3250s at
all six roll and knee joints 78 g heavier. The P × 4 table in §4 and the gates
in §8 and §9 were run on earlier plants: the armless CAD-inertial plant (1.67 kg) for the
walk, the lumped as-drawn get-up plant (2.10 kg, no bearings) for the arms. On
this plant with STS3215s at the hip rolls (2.224 kg), P × 4 on the rolls and
knees walks the four gate cases 4/4, with 32–37 mm of CoM margin, and stock
STS3215s still fall 0/4 (`docs/design-v6/no3250_walk_bearingA.txt`). With the
arms at their folded rest pose and self-collision on, no arm touches a leg in
any case; the robot's servo set (STS3250s at the hip rolls, the other rolls and
knees at 2.8×) stays up in 4 of 5 cases, and the μ 0.9 −15° turn falls
(`no3250_arms_walk_rest_folded.txt`).

The plant carries every part at its CAD inertia (`sim/build_v6_inertia.py`):
the printed parts from their STLs, each servo on its case mock at its CAD
place, the bearing as two rings split between the housing and the carrier, the
pack and boards as boxes. It is replaced by weighed masses once the parts
exist.

## 8. Walking

**First walk is open-loop**: `sim/static_gait.py` shifts the whole-robot CoM 5 mm
*inboard* of the stance sole centreline (so any drift falls toward the incoming
foot), swings the other foot on a sine arc, settles, and crosses over; joint
targets from the analytic IK (`sim/v6_kin.py`) at 50 Hz, min-jerk transitions
throughout. On hardware the same keyframes stream through the firmware's
`pose` path.

- **Cadence**: shift 1.6 s per 60 mm, swing 1.6 s, land 0.5 s — 5.25 s per 6 cm
  step. A step command is a fall; the swing leg lags its command ~0.3 s through
  the actuation lag and dead time, so the 0.5 s settle before the next shift is what
  separates a walk from a fall at the crossover. A 4 cm commanded lift gives
  15–25 mm of real clearance.
- **Turning** is walking in an arc: each swing foot is placed in a frame
  rotated from the stance foot and each leg is solved in its own yawed frame.
  Up to 20° of heading per step holds the same margins; the achieved heading
  is 10–15 % short of commanded (yaw-chain compliance), which a heading-aware
  controller closes.
- **Limits the gates found**: 5° of roll play fails at some friction values —
  hence the ≤ 3° requirement and ≤ 1° target per roll joint; a faster 1.2 s
  cadence loses the low-friction case.

**The policy comes after** the open-loop gait works on the floor (Gate E): trained
on the measured plant with the measured masses, stiffness and play in it —
[docs/training.md](docs/training.md).

## 9. Get-up

**Backward falls (supine) → the seat push with the arms**, a scripted sequence:
sit up with the arms folded up along the torso, plant the hands behind the
hips, tuck to hip −120° / knee −130°, and push (shoulder 90° → 0°, elbow −90° →
0°) while the ankles dorsiflex. On the as-drawn robot it stands, robust 6/6
(play 5°, μ 0.3–1.0, servos at 65–100 %), with 1° of margin on hip flexion (the
tuck needs ≥ 119°; the leg link's relief gives 120°). Config
`r5_asdrawn_rom120` in `sim/getup_v6_shoulder.py`.

**Forward falls (prone) are open.** The legs-only roll prone → side → supine
works on the bare body, but with the arms folded it fails 0/6 for every servo
choice — the arms block the roll. Candidates: an arm stow that clears the roll,
catching a forward fall on the hands, a one-arm roll.

**Paths that do not work**, each measured (full record in
[getup-decision-2026-09-17.md](docs/design-v6/getup-decision-2026-09-17.md) and
[getup-noappendage-2026-09-14.md](docs/design-v6/getup-noappendage-2026-09-14.md)):

| path | why not |
|---|---|
| legs only (≈ 150 sequences + continuous searches, deep flexion, kneel, pincer) | legs (0.335 m) are shorter than torso + head (0.55 m): every pivot on a leg contact lands the head, and below pelvis ~0.33 m no grounded pose puts the CoM over a sole |
| arms with reach ≤ 0.30 m | they push on the torso, not the floor behind the hips; the body pivots over the head |
| a third shoulder DOF; a one-arm side push; a prone push-up | 0 of hundreds of variants |
| no appendage at all: kip, bear, crow, bridge, rock-rise, a pelvis skid or rear bumper | the pelvis only lifts with a push from far behind the hips; a kip is bandwidth-bound under the deploy servo, not torque-bound. A hip −90…−100° crouch does keep the CoM 33–69 mm over the feet (full −125° flexion parks it behind the heel) — the target if a learned rise is ever tried |
| a tail at the hips | works in sim, rejected for the robot |
| a flat "bird" chassis with side-mounted hips | stands up in sim and is the documented fallback if the arm path fails on hardware, but needs a new chassis, hip and gait; most falls end on an edge |
| RL (PPO) reward shaping | reaches the kneel, never the rise (≈ 1.3 B steps) |

**Rules for get-up work**: search continuously before declaring a path dead;
verify a winner at 3× slower and across play, μ and servo strength; always run
with full self-collision; gate every idle pose of a hanging part in a walk; on
hardware, only with a sim margin, one motion per go, on the floor.

## 10. Validation method

Simulation can prove a design's capability before anything is ordered. The
gates, in order:

| gate | question | tool |
|---|---|---|
| A — kinematic capability | does a static single-foot stance exist, with margin, inside every joint limit and without self-contact? | `sim/design_gates.py` |
| B — actuator envelope | do the needed motions leave ≥ 2× speed and ≥ 1.5× torque at 11.1 V? | `sim/design_gates.py` |
| C — contact realism | does it survive μ 0.3–1.0, play as free travel, self-collision, the measured actuation lag and dead time? | built into D |
| D — open-loop capability | does the scripted walk (and get-up) hold across the adversity matrix? then: the same script on the bench | `sim/static_gait.py`, `sim/gate_no3250.py walk|sweep|envelope|arms|getup`, `sim/getup_v6_shoulder.py` |
| E — policy | only after D passes on hardware | [docs/training.md](docs/training.md) |

`tests/test_v6_design_gates.py` pins the plant, the IK and Gates A/B in the
pre-push suite.

**CAD gates** (`sh cad/run_checks.sh`): `cad/v6/check_assembly_v6.py` poses the
articulated assembly through every joint's range for every pair of pieces that
move relative to each other, checks the relatively fixed pairs that must keep
their distance (the neck floor over the pack) and every disc screw's thread
engagement, on the robot's build and the `ARMS=0` variant (results in
`docs/design-v6/cad_rom_check.txt`); printability audits report bridges,
ceilings and islands for the slicer's support settings; `cad/v6/animate_v6.py`
flies the parts in along their insertion paths to prove they assemble.

**Plants**: `sim/gen_plant_v6.py` builds a parametric plant (`DesignParams`) for
design sweeps; `sim/build_v6_inertia.py` builds the CAD-inertial plant of the robot as
drawn (17 actuators, arms at their folded rest pose, the servo set's masses,
the bearing housing, the hip-yaw bearings split between it and the carriers); `sim/bimo_biped_v6ar.xml` is the committed plant,
pinned by the tests.

## 11. Software

The software stack runs on hardware today and is shared by every body:

- **Firmware** (`firmware/`): the 50 Hz control loop on the ESP32 with the policy
  network in flash, a 250 Hz IMU sampler and attitude fusion, the command
  shaper, calibration in NVS, arming, fall and battery guards —
  [firmware/README.md](firmware/README.md), [docs/firmware-design.md](docs/firmware-design.md).
- **Link** (`link/`): a UDP protocol over Wi-Fi with a failsafe, and the
  consoles (`bimo_gui`, `bimo_tui`, `link/commander.py`) —
  [docs/control-channel.md](docs/control-channel.md).
- **Training** (`sim/mjx/`, `sim/walker_env.py`): brax PPO on MuJoCo MJX,
  graded by a CPU referee, distilled into the firmware —
  [docs/training.md](docs/training.md).
- **SIL** (`sim/sil/`): the real firmware code against the simulated plant —
  [docs/sil-harness.md](docs/sil-harness.md).

**The deployed policy is the 10-joint prototype's** (5 DOF per leg, no arms
or neck; plant `sim/bimo_biped_v5body.xml`, servo IDs 1–10). The training
envs and the referee also run on the robot's plant (12 leg joints driven, neck
and arms held, per-servo stiffness; [docs/training.md](docs/training.md) §13).
The firmware's bus side is the robot's 17 servos (calibration, `pose`,
telemetry, SIL ABI; the proposed ID map in
[docs/servo-map.md](docs/servo-map.md) §2.1), and the obs-spec generator
handles a robot run; a 17-servo bench test and a policy trained on the robot's
plant are open work (#81, #86).

## 12. Open decisions and open work

Everything open is a GitHub issue.

| decision | issue |
|---|---|
| servo set: the STS3250s' bench comparison and the per-ID gains | #73, then the purchase #74 |
| head: mono camera, or the stereo periscope | PR #71, #87 |
| make the code's defaults the robot to print: arms, the servo set, the 6810-2RS bearing, rollup and plant are done; the head follows PR #71 | #76 |

| work | issue |
|---|---|
| servo ID map, wiring, current budget | #77 |
| non-servo parts order | #78 |
| first print and fit check | #79 |
| assembly guide with figures | #80 |
| firmware port to 17 joints (with the register-21 check at boot) | #81 |
| measured plant, then the open-loop floor sequence | #82 |
| shoulder overload margin | #83 |
| scripted get-up on hardware | #84 |
| get-up from prone | #85 |
| training stack port (Gate E) | #86 |
| Pi and head camera integration | #87 |
| goal-conditioned locomotion | #88 |
| servo model: overload cutoff, sag, thermal | #6 |
| exteroceptive observation | #11 |

## 13. Build sequence

0. **Bench, no purchase** (#73, [experiments/plan-b-bench/](experiments/plan-b-bench/)): one spare STS3215 — read registers 21/22/23;
   torque off, write P 32 → 64 → 96 → 128 → 160 with D scaled (128 is exactly
   4 × 32, so 160 shows which side of the line it falls); measure stiffness from
   Present Position with 0.5 / 1.0 / 1.5 N·m on a lever; hold a leg-like
   inertia and watch for buzz; confirm the protections don't trip.
1. **Stance test**: that servo in a hip-roll mount, 8° of roll with a planted
   foot; pass ≤ 0.3° short at load 120 (≤ 0.4° on the 3× route).
2. **Buy** the STS3215s (15 needed, 12 on hand, plus spares), the two
   STS3250s for the hip rolls (ordered 2026-10-02, #74), the two generic
   6810-2RS bearings (ordered 2026-10-06; measure them on arrival), and the
   non-servo parts ([docs/bom.md](docs/bom.md)).
3. **Configure** P and D per ID; record them in `docs/servo-map.md`.
4. **Print and assemble** ([cad/PRINT_LIST.md](cad/PRINT_LIST.md),
   [docs/assembly.md](docs/assembly.md)); weigh every part; measure play per roll
   joint (≤ 3° required, ≤ 1° target).
5. **Put the measurements in the plant** and re-run the gates
   (`gate_no3250.py walk | sweep | arms | getup`).
6. **Floor sequence, over the tether, one motion per go**: stand → crouch →
   shift → one-foot → step in place → six steps; each step a margin, clearance
   and slip number against the sim's. Then the scripted get-up.
7. **Gate E**: train a policy on the measured plant.

## 14. Design principles

- The servos are the skeleton: geometry comes from the vendor's STEP and
  datasheet, never from photos.
- Bench before policy. Measure a margin on the body before asking a policy to
  find it.
- Model a term only after the bench has measured it; a guessed
  domain-randomization range makes a policy robust to a thing the robot does
  not do.
- Calibrate the simulation where the question lives, and run the deployed
  actuation chain (lag, dead time, ticks, play) inside every gate.
- Stiffness of the roll chains is the whole game: double-support every roll
  joint, thread-lock horn screws, measure play per joint before the first walk.
- Every relatively-moving pair is enumerated and swept; a pair that is not
  listed is a pair that was never checked.
- Supports are the slicer's job; model printable geometry, not support slabs.
- Dynamic tests on hardware need the sim margin first and a go per attempt.

## Source-of-truth files

| what | file |
|---|---|
| every CAD dimension | `cad/v6/dimensions_v6.py` (servo interface from `cad/dimensions.py`) |
| the parts | `cad/v6/*.py`, exported to `cad/v6/stl`, `cad/v6/step` by `cad/v6/parts_v6.py` |
| the assembly and ROM gate | `cad/v6/assembly_v6.py`, `cad/v6/check_assembly_v6.py` |
| the plant | `sim/gen_plant_v6.py`, `sim/build_v6_inertia.py` → `sim/bimo_biped_v6ar.xml` |
| gait, IK, gates | `sim/static_gait.py`, `sim/v6_kin.py`, `sim/design_gates.py`, `sim/gate_no3250.py` |
| get-up | `sim/getup_v6_shoulder.py` (with `sim/getup_v6.py`) |
| records and evidence | `docs/design-v6/` |

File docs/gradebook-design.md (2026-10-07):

# Gradebook — a Jev-style configurable grader to replace the LLM referee

**Status:** v1 shipped 2026-10-07 (this PR) — design doc + trace capture + metric grader
**Author:** Aime · **Date:** 2026-10-07 (adjudicated Tom 2026-10-07)
**Lives in:** `sim/gradebook/` + this file at `docs/gradebook-design.md`
**Goal:** take over Claude's referee duties with software; emit numerical, per-criterion feedback an RL pipeline can use.

---

## 1. Problem

Today's referee is a conversation, not a pipeline stage. Claude's reads (qualitative verdicts, per-scenario takes, "the movement reads natural") sit *outside* the machine. The machine's own evidence is:

* `RUN/seed_log.jsonl` — terminal JSON per episode, written after the fact, no trace, no per-criterion numbers.
* `RUN/scorecard{,_lag,_sil}.json` — one row per scenario; verdict = `successes == n` plus headline metrics.
* `RUN/reel_index.json` + `.mov` — the reel Claude watches.

What grading must produce that it doesn't today:

1. **Per-criterion verdicts with numbers** — *why* something passed/failed, comparable across runs, plottable, diffable.
2. **Numbers usable in RL** — a graded output that can serve as reward, shaping signal, or offline selector.
3. **Configurable criteria** — grading is a versioned data artifact (YAML), not edits scattered through `eval_precision.py` scenario factories.
4. **A referee you can argue with** — the grade card shows the evidence behind every verdict, so a FAIL can be contested and the grader can't paper over a failure (Claude's honesty rules, enforced by schema instead of by Claude).

## 2. Anchor decision: a Jev-like RETURN interface, judge-model-agnostic

What's Jev-like is the interface **from the grading model back to the referee/RL function**: every criterion returns as a typed answer — scalar or ordered-level index, per-level `probabilities`, a `confidence`, evidence refs — assembled into a versioned grade card. That answer schema is the stable contract; RL reward code reads it and doesn't care what model produced it. Nothing in the reward path changes when the grading model swaps.

The grading model itself is pluggable — deterministic metric evaluators, an LLM judge reading the trace, or a **vision-capable judge watching reel frames/clips**. Jev specifically cannot take visual input, so it's one option among several (claude-consult and the local aux-vision model are, today, the vision-capable judges; §2.1). Where the request side borrows Jev's shape (one episode state in, typed questions out, evaluated in parallel, in isolation), it's our own criteria YAML that builds those questions — a symmetry, not a dependency.

### 2.1 Grader input modality: state data, not pixels

Is the grader watching video or reading a vector? Vector-first everywhere:

* **`metric` criteria read the Trace** — per-episode numeric arrays captured at control dt from the MuJoCo state (qpos/qvel/up_z/height/planar), plus command schedule, contacts, fall/recovery events, servo/power telemetry. Produced by capture-side hooks inside the scenario factories *during the rollout*. Physics state, never pixels — no renderer in the grading path.
* **Judge criteria can take visual input.** Vision-capable judge backends (`claude-consult`, local aux vision) get a `state: {frames: n}` projection — sampled referee-reel frames or clips, already produced by the render path. Jev cannot take images; a Jev-judged criterion falls back to the text projection of the Trace (summary, fall timeline, series stats — `key_frames: n` there are numeric snapshots, not pixels). The criteria YAML's backend table decides which graders are offered which state.
* **v1 still ships metric-only.** Subjective reads start as trace numerics (wobble_rms, up_z variance, foot_slip, power) — precedent: a render has read clean while a numeric check caught real displacement, and vectorized criteria are what make the numbers train-compatible. Visual judging arrives with the judge backends (v2), one criterion at a time, through the trust ladder.

## 3. Architecture

```
run artifacts (scorecard, seed_log, reel)  or  live rollout (CPU referee / MJX)
        │
        ▼
[1] TRACE — one Trace object per episode: state history at control dt
    (qpos/qvel/up_z/height/planar), command schedule, fall/recovery
    events, contact summary, servo/power telemetry, scenario headline.
    One extractor per source kind; capture-side hooks inside the
    scenario factories (see §7.3 risk).
        │
        ▼
[2] CRITERIA SPEC — a versioned YAML artifact (see §4). The only thing
    edited to change what's graded.
        │
        ▼
[3] GRADING ENGINE — compiles spec → typed questions per episode; routes
    each criterion to its backend; evaluates in parallel, in isolation;
    gates/normalizes/weights; aggregates.
        │
        ▼
[4] GRADE CARD — runs/<run>/grade_v{n}.json + .md (the referee read).
    Per-criterion value/level/probs/confidence + evidence refs;
    per-scenario and per-run aggregates.
        │
        ▼
[5] CONSUMERS — nightly champion selection (numerical), RL reward adapter,
    marimo training-inspector notebook, tracking dashboard.
```

The **Trace is the load-bearing interface**: every criterion can only grade what the Trace carries, so the trace schema is designed as carefully as the API. Today verdict logic computes intermediates *during* rollout and drops them; making the factories write evidence into the Trace as they compute it is the critical-path item of the build.

### 3.1 Deliverable slices

| Slice | Ships | Why |
|---|---|---|
| **v1 — gate** | Trace extractor; metric criteria only; grade card JSON+MD; parity vs existing scorecards | No LLM calls, cheap, deterministic; already improves on "successes/n" by grading per criterion |
| **v2 — judges** | Judge backends (`jev`/`claude-consult`/`local`) behind one adapter; rubric criteria for the subjective reads; confidence handling | Covers the judgment calls Claude makes today |
| **v3 — RL** | Episode-level reward adapter; dense-shaping compiler from the same spec | The RL payoff; needs the card stable first |

## 4. Criteria spec (versioned YAML)

```yaml
version: 1
suite: referee_v2                     # names + version survive in every card
judges:                               # backend table; criteria name their backend
  metric: {}
  jev: {model: jev-latest}
  claude: {consult: true}

criteria:
  # ---- metric: deterministic code over the Trace -----------------------
  success:
    type: metric
    source: scenario                  # the scenario's own success test
    weight: 4.0
    score: {normalize: [0, 1]}        # 1.0/0.0 per seed; mean across seeds
  upr:                                # upright quality
    type: metric
    source: trace
    path: up_z
    aggregate: min                    # worst up_z over the episode
    weight: 2.0
    score: {direction: higher_better, normalize: [0.4, 0.95]}
  cot:                                # cost of transport (loco)
    type: metric
    source: shared_metrics
    metric: cot
    weight: 1.0
    score: {direction: lower_better, normalize: [0.4, 2.0]}
  foot_slip:
    type: metric
    source: shared_metrics
    metric: foot_slip
    weight: 1.0
    score: {direction: lower_better, normalize: [0.0, 0.08]}
  wobble:
    type: metric
    source: shared_metrics
    metric: wobble_rms
    weight: 1.0
    score: {direction: lower_better, normalize: [0.0, 1.0]}

  # ---- rubric: judge scores ordered levels ------------------------------
  gait_naturalness:
    type: rubric
    backend: jev                      # or claude / local
    levels: ["rigid, robotic", "adequate", "smooth, biological"]
    state: {trace_summary: brief, key_frames: 8, power_headline: true}
    # key_frames = 8 numeric state snapshots at chosen times, NOT camera
    # frames; a `frames: n` key samples real reel pixels for
    # vision-capable backends only (v2+, see §2.1)
    weight: 1.0

  # ---- check: judge probability of a statement ---------------------------
  reads_stumble:
    type: check
    backend: jev
    statement: "The gait contains a stumble or loss-of-control moment"
    state: {key_frames: 8, up_z_series: true}
    weight: 1.0

defaults:
  weight: 1.0
  min_confidence_in_reward: 0.5      # confidence gating for judge criteria
```

Notes:

* `normalize` windows are calibrated data, not magic — seeded from historical scorecard distributions, re-tuned during shadow week, versioned with the spec.
* Criterion evaluation is **in isolation**: a failure in one criterion errors/labels that one, never poisons the rest.
* The v1 criteria catalog (drawn from what the referee already computes) is Appendix A.

## 5. Grade card (versioned, machine-readable)

```json
{
  "spec_version": 1, "suite": "referee_v2",
  "run": "loco_v29zero", "scenario": "line_1m", "seed": 1,
  "criteria": {
    "success": {"value": 1.0, "level": "pass", "confidence": 1.0},
    "upr":     {"value": 0.93, "normalized": 0.86, "weight": 2.0},
    "cot":     {"value": 0.71, "normalized": 0.64, "weight": 1.0},
    "gait_naturalness": {"value": 1.43, "probs": {"0": 0.11, "1": 0.60, "2": 0.29},
                          "confidence": 0.57, "backend": "jev"}
  },
  "aggregate": {"total": 7.93, "normalized_total": 0.81, "fell": 0},
  "evidence": {"trace": "runs/loco_v29zero/traces/line_1m_s1.npz",
               "reel_chapter": {"scenario": "line_1m", "t": [12.0, 26.0]},
               "headline": "8/8 | wobble 0.41 | 7.2 W"}
}
```

Two card documents per run:

* `grade.json` — machine: nightly selector, RL adapter, dashboards.
* `grade.md` — human: the referee's read. Criteria rows with verdicts + numbers, rubric commentary in its own section, FAIL takes labeled FAIL, evidence links into the reel via `reel_index.json` chapters.

`grade_manifest.json` indexes cards per (spec_version, backend set) so old cards stay retrievable. One manifest row per card: spec_version + suite + one-line summary.

**Aggregation for selector/RL:** per-scenario `total = Σ w_c · norm_c` (mean across seeds); run-level `normalized_total` = weighted mean across scenarios, plus per-family rollups (`loco`/`skills`/`getup`). Scenario-family filtering follows the existing `FAMILY_SCENARIOS` rules.

## 6. RL adapter

* **v1 (episode-level):** `R_ep = Σ_c w_c · norm_c(Trace)` — a proper per-episode scalar. Usable three ways: (a) offline selector — nightly champion = max grade total (ties broken by fall count, then CoT); (b) return labels in offline data; (c) reward-model training data.
* **v2 (dense shaping):** a compiler turns the same criteria YAML into per-step reward components for the training env (this is where `w_track_v`, `w_upright` etc. would move). Same spec, train/eval consistency for free. Explicitly later — get the episode-level number proven first.
* **Confidence gating:** judge-type criteria only enter reward after shadow-week validation; below `min_confidence_in_reward` they're down-weighted or excluded. Judge criteria never silently fabricate a number — schema requires a backend field and errors stay per-criterion.
* **Economies conditioned on completion (from the 2026-10-07 night grading):** CoT/power on early-terminated (fell) episodes are misleading — a policy that falls in 3 s racks up a *better* CoT than one that walks the full 14 s. Economy columns get a `condition: completed` flag in the spec (fall-seeded episodes inherit the worst-case norm), or the selector fallback ordering handles it (fall count before CoT).

## 7. Training inspector (marimo notebook)

Tom's add: it must be easy to *see* what training is doing. A **marimo notebook** ships with the grader (`sim/gradebook/inspect_gradebook.py` — marimo notebooks are plain `.py`, reactive, no hidden cell state) reading only already-versioned artifacts:

* **Grade-card trends:** `normalized_total` and per-criterion scores across successive nightly runs; champion lineage; fall rate & CoT overlays.
* **Per-scenario breakdown:** criteria heatmap (scenario × criterion), seed spread, judge confidences once v2 lands.
* **Trace inspector:** `up_z`/height/planar-vs-t for any (scenario, seed), fall/recovery markers, command schedule — one reactive selector drives every plot.
* **Side-by-side run compare** for champion-vs-candidate; reel clip/filmstrip embed for the selected episode (the render path already exists).

No new capture for the notebook's sake — it's a read-only consumer of grade cards, traces, and reels, so it inherits versioning (`spec_version` selector) instead of fighting it. The reactive marimo model fits the referee loop: change the run selector and every downstream cell recomputes, no stale-notebook trap.

## 8. Migration & integration

* **Additive.** Existing scorecards are frozen and stay comparable (the 144-seed totals). Grade cards are new files (`grade_v{spec}.json/.md`) under `runs/<run>/`. The grader never writes to a scorecard file.
* New scenario = YAML entry; the frozen registry in `eval_precision.py` stays, and each card row declares its mapping to the frozen registry names so old cards keep meaning what they meant.
* Wiring: `eval_precision.py --grade [spec.yaml]`; nightly cron passes the champion's criteria spec explicitly. Default-on only after the parity gate.
* **Claude keeps:** rubric authoring (drafting criteria YAML when a new judgment call appears), contesting grade cards, auditing reels. **Claude loses:** the judging seat — verdicts come from the card.

### 8.1 Trust ladder (before the grader displaces Claude in the nightly loop)

1. **Shadow week:** grader runs alongside Claude's reads; agreement measured on the frozen criteria set; disagreements reviewed, criteria/normalization tuned. (Run-length configurable, not hard-coded.)
2. **Gate+audit:** the automated grader picks the champion; Claude spot-checks cards on the nights he reads anyway.
3. **Automated gate:** Claude only audits on request. Disagreement > threshold (YAML-tunable) still pages for review.
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

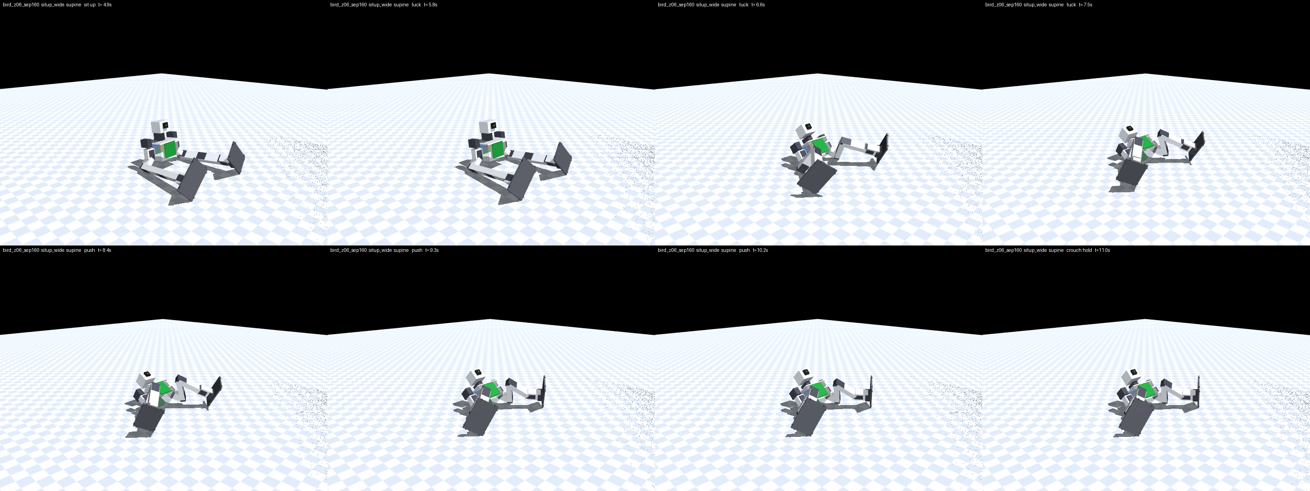
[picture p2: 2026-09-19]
docs/design-v6/getup_side_supine_strip.png

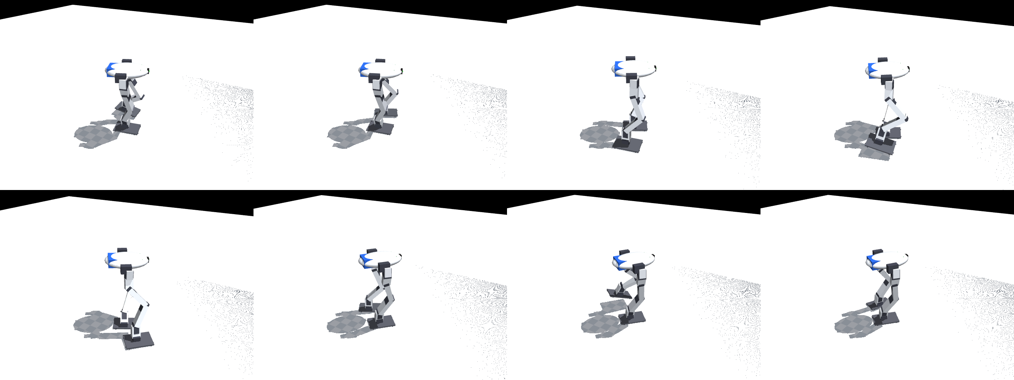
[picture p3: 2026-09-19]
docs/design-v6/gateD_wide_gait_bird3_combo_turn15_strip.png

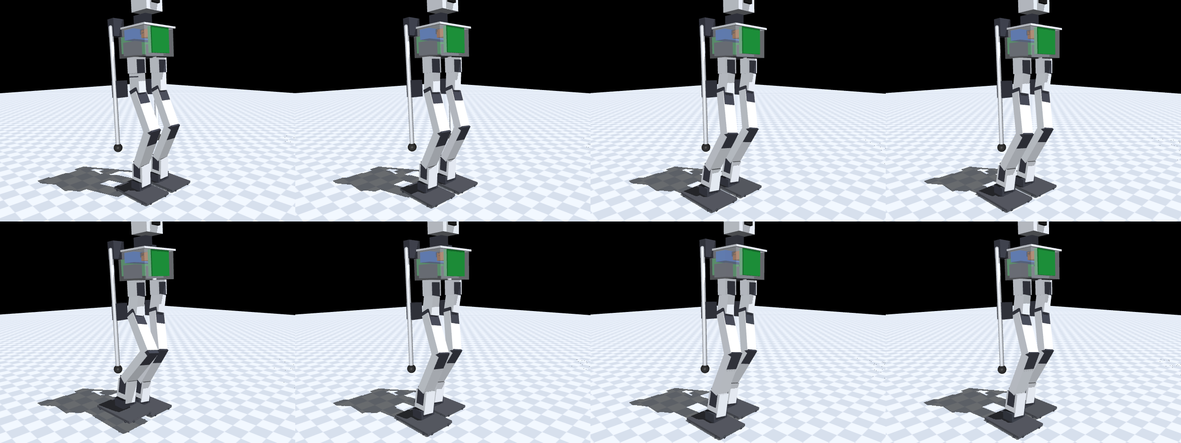
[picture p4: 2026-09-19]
docs/design-v6/getup_shoulder_arm16x16_elbow_aft_walk_strip.png

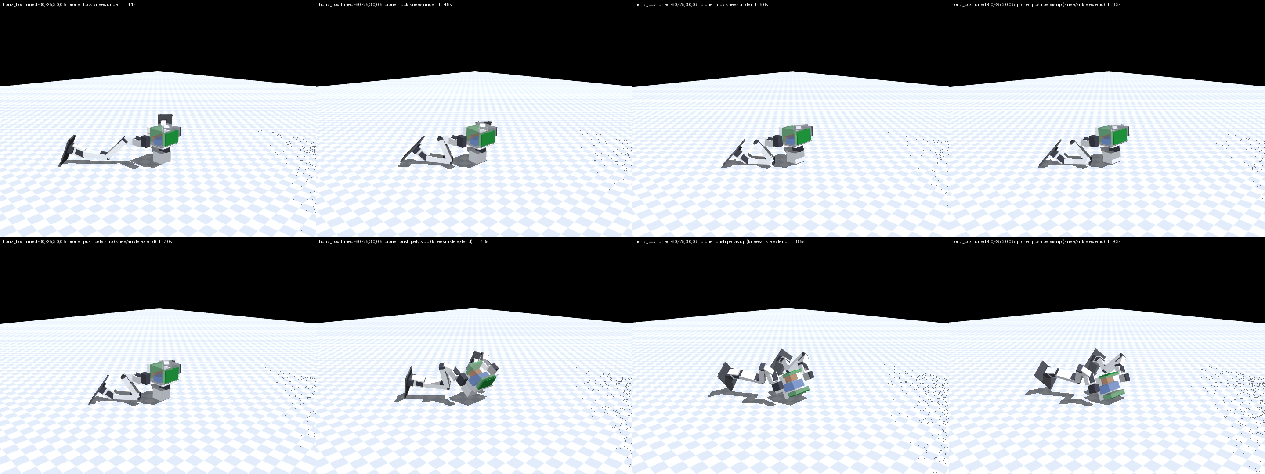
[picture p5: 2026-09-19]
docs/design-v6/getup_side_h_prone_strip.png

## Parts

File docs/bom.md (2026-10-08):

# Bill of materials

Everything needed to build the robot described in [DESIGN.md](../DESIGN.md): 17
servos, the controller board, a Raspberry Pi 4B and its head camera, a 3S pack
and its protection, fasteners, filament and tools. The printed parts are in
[cad/PRINT_LIST.md](../cad/PRINT_LIST.md); how it goes together is
[assembly.md](assembly.md); power and wiring detail is [wiring.md](wiring.md).

**Status.** Nothing for the robot has been bought. The servo purchase waits on
the bench test in issue #73, then #74. The non-servo order is #78.

**Buying rules**

- **Buy to the spec filter in each row, not to a listing.** Listings churn: a
  pack the prototype was designed around disappeared mid-project. Anything that
  meets the filter fits. A cached listing title is not a live listing, so check
  stock and price in a browser.
- **Electronics need real manufacturer documentation**: a datasheet with specs
  and a connector or outline drawing. Reseller renders and self-authored
  "manuals" do not count. When one is bought, mirror its datasheet into
  `docs/datasheets/`. The rule is for electronics only: mechanical and passive
  parts (bearings, mirrors, fasteners) can be generic. Measure any dimension
  the CAD depends on when the part arrives, and put the measured value in the
  design.
- Prices are indicative and dated, and none has been re-checked.

In the **have** column, *on hand* means the repo's records say it is in the
lab. A blank means buy it.

## 1. Servos

| item | qty | spec | have |
|---|---|---|---|
| **Feetech STS3215, 12 V class: ST-3215-C018** | 15 + spares | 12 V, 30 kg·cm; case 45.22 × 24.72 × 35 mm; 55 ± 1 g; 25T spline; half-duplex TTL bus; 5264 3-pin connector with a 150 mm lead | **12 on hand** (10 of them are in the prototype today) |
| **Feetech STS3250 (ST-3250-C001 / C002)** | 2 | the two hip rolls; same case, horn and connector; 12 V, 50 kg·cm, 74.5 ± 1 g | **2 ordered** 2026-10-02 (#74) |

- **Why 15 + 2:** 12 in the legs, the neck, and 4 in the arms, with the two hip
  rolls on STS3250s ([DESIGN.md §4](../DESIGN.md)). How many STS3215s to buy,
  with spares, is #74.
- **Datasheet, drawing and STEP model:** `docs/datasheets/st3215/` and
  `cad/vendor/ST3215.step`.
- **Never buy the 7.4 V class** (STS3215 C001, rated 4–7.4 V). It cannot run
  on 3S. Both classes share one case, so the model number on the label is what
  tells them apart.
- **Sources:**
  - Waveshare direct, <https://www.waveshare.com/st3215-servo.htm>. Choose the
    12 V / 30 kg·cm version. It was $21.99 on 2026-07-11.
  - Amazon RCmall 6-pack, B0FLPQQ4FR. This listing was checked and is the
    12 V class.
- **Gain setup** ([DESIGN.md §4](../DESIGN.md)): on the four ankle-roll and
  knee STS3215s, raise the position-loop P (register 21, default 32) and set D
  (register 22) to the values #73 establishes (the sim assumes P 96 / D 0,
  ≈ 2.8×). Record the values per ID in [servo-map.md](servo-map.md).

**Incoming check.** Run it on every servo before it shares the bus with another:

1. **Weigh it and read the label.** An STS3215 weighs 55 ± 1 g and its label
   reads ST-3215-C018.
2. **Read Model_Number, alone on the bus.** Servos ship as ID 1, and two
   servos with the same ID do not enumerate.
   - The register is address 3, 2 bytes, little-endian.
     `firmware/components/scsbus/include/scsbus/registers.h` names the two bytes
     `kRegServoMajor` / `kRegServoMinor`.
   - **Expected values:** STS3215 = 777, STS3250 = 2825. These come from
     Feetech's model numbering as found during sourcing.
   - **Confirm the read on an on-hand STS3215 first.**
   - A read is not a motion command. Opening the serial port does reboot the
     board, though, so drain it before sending anything
     ([AGENTS.md](../AGENTS.md), bench safety).

*Why:* a relabelled or clone servo silently invalidates the stiffness
measurement the whole servo plan rests on.

**If #73 fails.** The fallbacks come in DESIGN.md §4's order, after trying the
I term. Both are the same case, horn and protocol, so no CAD change:

| item | qty | spec | role |
|---|---|---|---|
| Feetech STS3235 (ST-3235-C001) | 1 | 12 V, 30 kg·cm, 70.5 g, aluminium case, steel gears 1:345, backlash ≤ 0.5°, 2.7 A stall (Feetech spec A/0, 2021-11-19) | shows whether the gear train, not the loop gain, is what is soft |
| Feetech STS3250 (ST-3250-C001 / C002), beyond the two hip rolls | up to 4 more (ankle rolls, knees) | 12 V, 50 kg·cm, 74.5 ± 1 g, aluminium case, 4.2 A stall, measured loaded backlash 0.33° (third-party bench) | only if the bench comparison (#73) calls for them |

**STS3250 sources** (checked 2026-09-26):

- **Feetech direct on Alibaba.** The storefront is feetechrc.en.alibaba.com
  (supplier Shenzhen Feite Model Co., Ltd., Feetech's own company); the listing
  is 1601808172007.
  - $47.77 each for 2–9, $45 for 10–99, minimum order 2.
  - US shipping and import charges are included. Delivery is slow (quoted
    October to December).
  - The C001 / C002 / URT variants share one price ladder.
- **WowRobo** (Dongguan; sells LeRobot kits): $43 for the C002. The stock count
  is hidden, and US duties are not published on the servo page.
- **Avoid:**
  - AliExpress. The Feetech Official Store there is genuine, but the servo SKU
    costs $80.86 plus about 40 % import charges at checkout, and the listings
    headline the URT-1 board instead.
  - US resellers at $65–97: BABSCO $64.99 (out of stock), Amazon $67–75,
    AIFITLAB $88–97.
  - Any listing that gives the mass as about 50 g.
- **Incoming check:** 74.5 ± 1 g, an aluminium case, a label reading
  STS3250-C00x, and Model_Number 2825. Feetech's STS3250 datasheet is not yet
  in `docs/datasheets/`.

Feetech's TTL catalogue lists exactly three 12 V servos in this case (checked
2026-09-26): ST-3215-C018, ST-3235-C001 and ST-3250-C001. Ruled out:

- the RS485 SM series, because the General Driver's bus is TTL;
- 7.4 V parts, because a 3S pack is over their rating;
- anything without a manufacturer datasheet.

## 2. Controller, computer, camera

| item | qty | spec | have |
|---|---|---|---|
| **Waveshare General Driver for Robots** | 1 | ESP32 with onboard QMI8658C IMU, AK09918C magnetometer and INA219 (0x42); two servo ports H5/H6 (pin 1 DATA, 2 DC_IN, 3 GND); power inlet XH2.54 2-pin; outline 65.01 × 56.01 mm, holes 58 × 49 mm | **on hand** (in the prototype today) |
| Raspberry Pi 4B | 1 | 2–4 GB; 85 × 56 mm, M2.5 holes on 58 × 49 mm | not recorded |
| Pi heatsink | 1 | low profile, no fan: it must stay within the 16 mm the USB/Ethernet stack already occupies above the board | |
| microSD card | 1 | 32 GB | |
| Raspberry Pi Camera Module 3 **Wide** | 1 | Sony IMX708, 102° horizontal / 120° diagonal field of view; 25 × 24 × 12.4 mm; M2 holes on 21 × 12.5 mm; 15-pin 1 mm FPC | |
| camera cable | 1 (+1 spare) | Raspberry Pi 15-pin 1 mm FPC camera cable, **≥ 300 mm** | |

- **General Driver.** Its documents are in `docs/datasheets/general-driver/`.
  - The outline comes from the dimension drawing; the wiki's "65 × 65 mm" is
    wrong.
  - The input rating is 7–13 V on the wiki but "DC 9–12.6V" on the rev 1.2
    silkscreen. A 3S pack is inside both.
- **Pi 4B.** It slides vertically into the pelvis's aft column.
- **Camera cable.** The camera ships with a 200 mm cable, too short. The route
  runs from the Pi's CSI edge under the deck up to the head, plus a slack loop
  for ±90° of neck yaw. 300 mm is the design estimate; the routed length has
  not been measured.

The Pi ↔ ESP32 link is not chosen yet (#87).

**On hand, not in the build:** a Teyleten GY-BNO085 IMU breakout. It is the
upgrade path if the onboard IMU proves insufficient, and would plug into the
board's I²C header P1.

## 3. Power

The power path runs pack → protection board → fuse → switch → board inlet. A
bulk capacitor sits at the board, and a 5 V buck feeds the Pi.

**Current is open (#77):**

- The General Driver's XH inlet contact is rated **3 A**.
- Waveshare's FAQ limits the board's servo power path to **5 A continuous**
  (about 5 STS3215s, not stalled at once).
- The robot puts 17 servos on that path. The prototype measured 6.8 A peaks on
  10.
- The fix under consideration is to solder the power lead to the inlet pads
  instead of using the XH plug.
- The fuse, the bulk capacitor and a current budget are required before the
  first powered floor run.

| item | qty | spec / filter | have |
|---|---|---|---|
| **3S LiPo pack** | 1–2 | **11.1 V, not 11.4 V HV**; 2200–2600 mAh; **≤ 105 × 36 × 26 mm**; 150–190 g; XT60 or XT30; ≥ 25C | |
| **3S protection board** | 1 | ≥ 15 A continuous; over-discharge cut-off ≈ 3.0 V/cell; balance leads; must fit the pelvis power pocket together with the buck | |
| **5 V / 5 A buck** for the Pi | 1 | Pololu D24V50F5 (item #2851): 6–38 V in, 5 V, 5 A; 17.8 × 20.3 × 8.8 mm; two 2.18 mm holes for #2/M2 screws on 13.5 × 16.0 mm | |
| inline fuse holder | 1 | mini blade (ATM), 16–18 AWG leads | |
| mini blade fuses | 1 pack | 10 A and 15 A | |
| bulk capacitor | 1–2 | 470–1000 µF, ≥ 25 V, low-ESR, 105 °C electrolytic | |
| power switch | 1 | inline, rated at least the fuse current | |
| balance-lead low-voltage alarm | 1–2 | 1S–8S, plugs onto the JST-XH balance lead, per-cell display, settable alarm point | |
| 3S balance charger | 1 | with a storage mode | check what is on hand |
| inline watt meter | 1 | ≥ 60 A, XT60/XT30, shows peak current | |
| LiPo charging bag | 1 | fits the pack | |

- **Pack**
  - The pelvis battery layer is sized to this envelope (`BATT` in
    `cad/v6/dimensions_v6.py`, with 170 g modelled).
  - An HV pack charges to 13.05 V, above the 12.6 V the servo listing and the
    board's silkscreen allow.
  - 2600 mAh packs usually run over 105 mm long, so 2200 mAh is the class that
    fits.
  - Two candidates from the sourcing pass:
    - The Admiral EPR22003X6 (105 × 34 × 22 mm, XT60) fits.
    - The Yowoo 3S 2200 (105 × 36 × 26 mm, XT60) fits the box but is listed at
      208 g, over the mass filter.
  - Cross-check dimensions and mass at two independent stockists.
- **Protection board**
  - The pocket takes both boards standing on edge: one 60 × 25 mm face,
    8.4 mm deep (`PWR_BOARD`).
  - No board is selected yet.
  - The UART "smart" boards that give per-cell telemetry do not fit the pocket:
    JBD SP04S010 (80 × 60 × 12 mm) and Daly R05J (100 × 65 × 13 mm).
- **Buck**
  - Pololu lists it 8.8 mm thick, against the pocket's 8.4 mm depth. Check the
    fit.
  - Its holes take #2/M2 screws, but the pocket's two bosses are M2.5 pilots.
    How the power boards are fixed is open.
- **Fuse:** start at 15 A, and drop to 10 A only once the peak current has been
  measured. It is for a dead short, not the operating current. **Never use a
  polyfuse/PPTC**: it takes seconds to trip, and its series resistance sags the
  rail.
- **Bulk capacitor:** solder it across the servo bus at the board, observing
  polarity. It must be rated 25 V because a full 3S pack is 12.6 V.
- **Power switch:** the board's own slide switch SW1 sits in the servo path,
  but the schematic does not state its rating.
- **Low-voltage alarm:** it is the only protection that is independent of the
  firmware, and it is per cell. One weak cell hides inside a normal-looking
  pack voltage.
- **Charger:** storage-charge to 3.8 V/cell if a pack will sit for more than a
  few days.
- **Watt meter:** it measures the peak current #77 needs, and that number sets
  the fuse.

**Not needed:**

- a UPS HAT. The Waveshare UPS Module 3S's pack output is 2 A, an order of
  magnitude under the servo bus.
- an anti-spark connector. At 3S the connection arc is negligible.
- PCA9685-type servo boards. They drive PWM servos and cannot talk to ST/SC bus
  servos.

## 4. Leads and connectors

| item | qty | spec | notes |
|---|---|---|---|
| pack pigtail | 1 | XT60 or XT30 to match the pack; ≥ 20 AWG silicone lead | runs to the protection board, fuse and switch |
| board power pigtail | 1 + 1 spare | JST XH 2.54 mm 2-pin female (housing XHP-2, SXH contacts), pre-crimped, 22 AWG, ≥ 100 mm | for the General Driver inlet (connector diagram no. 10, silkscreen "− +") |
| servo extension leads | ~4 | 3-pin 5264 bus-servo cable, 200–300 mm | each servo ships with a 150 mm lead |
| Pi power lead | 1 | USB-C pigtail from the buck (or the Pi's 5 V GPIO pins) | |
| silicone wire, heat-shrink | — | 20 AWG for the power path | |
| USB-C data cable | 1 | for flashing the General Driver | likely on hand |

- **Board power pigtail.** XH crimps take 22 AWG at most, so splice the pigtail
  to the 20 AWG lead and heat-shrink the joint. Pigtail wire colours are not
  standard: check polarity against the silkscreen. This is not a balance-lead
  connector.
- **Servo extension leads.** Which hops need them has not been measured on this
  robot (#77). On the prototype, the hip-roll → hip-pitch hop routed at 170 mm.

## 5. Hip-yaw bearing

A thin-section bearing between each yaw carrier and the bearing housing
screwed under the pelvis ([DESIGN.md §5.2](../DESIGN.md); background:
[study-yaw-bearing.md](design-v6/study-yaw-bearing.md), option A):

| bearing | qty | spec | have |
|---|---|---|---|
| **6810-2RS**, 50 × 65 × 7 mm, rubber-sealed deep-groove | 2 | inner race on the carrier hub (+0.08 mm), outer race in the bearing housing's recess (−0.04 mm) | **2 ordered** 2026-10-06: generic, no brand, USA Bearings & Belts, $16.04 each ([listing](https://usbearingsandbelts.com/products/6810-2rs)) |

- **Generic, so measure on arrival:** OD, bore and width (65 / 50 / 7); the
  outer ring's inside diameter at the seal (D2), which must be under 62.6 so
  the housing's shoulder bears on the outer ring face and not the seal; the
  inner ring's outside diameter at the seal (d1); the radial and tilting play
  by hand (the bearing is there to remove yaw play); the weight. Put the
  measured values into `cad/v6/dimensions_v6.py` (`YAW_BRG_*`) and re-run the
  CAD gate before printing the housing. Until then the CAD carries SKF's
  published 61810-2RS1 values: d1 ≈ 54.67, D2 ≈ 61.8, Da max 63, r1,2 min
  0.3, C 6.76 / C0 6.8 kN, 0.053 kg
  ([SKF sheet](https://docs.rs-online.com/f06f/A700000007138802.pdf)).

- **Retaining compound**, on both seats: Loctite 641 (medium strength, fills a
  0.15–0.25 mm gap, can be taken apart), or 648 if it never needs to come
  apart. The CAD's 0.04 / 0.08 mm interference fits are inside the printer's
  error band, and PETG creeps.
- **6710-2RS (50 × 62 × 6 mm)** can replace the 6810 if its rating is
  confirmed. Only `YAW_BRG_W` and `YAW_BRG_OD` in `cad/v6/dimensions_v6.py`
  would change.

## 6. Fasteners

The counts come from each part module's `SCREWS()` (the robot's build, with
arms), times the number of each part.

**The build uses no heat-set inserts and no washers.** All servo-case and
printed-pilot screws are M2.5 flat-head self-tappers. The servo case holes take
M2.5, not M3.

| fastener | qty | where | have |
|---|---|---|---|
| **M2.5 × 8 flat-head (90° countersunk) self-tapping**, stainless | **111** | leg links 24, ankle links 12, feet 12 (tabs 8, near-row bosses 4), yaw-carrier walls 16, bearing housing to the pelvis 5, neck floor to the neck tube 4, neck-servo stators 4, head face 4, girdle to deck 10, shoulder servos 8, elbow grips 12 | **24 on hand** |
| M2.5 × 5 flat-head self-tapping | 8 | yaw-servo stators: 2.6 mm through the cell ceiling, 2.4 mm into the idler-face holes (3.0 deep in the vendor STEP; an × 8 would bottom out) | |
| M2.5 × 10 pan self-tap | 4 | Pi and General Driver, lower row, into standoff bosses | |
| M2.5 × 6 pan self-tap | 4 | Pi and General Driver, upper row, into wall pilots | |
| M2.5 × 8 pan self-tap | 2 | the power-pocket bosses | |
| M2 × 4 self-tap | 4 | Camera Module 3 onto the head face | |
| **M3 button head, disc screws** | **116** = 56 × M3×5 + 52 × M3×6 + 8 × M3×8 | 4 per servo disc | **40 M3 × 6 on hand** |

- **Disc screw lengths.** The horn and idler discs are tapped through a thin
  flange: 2.5 mm on the horn and 2.1 mm on the idler, measured on the bench and
  confirmed on the vendor STEP.
  - A disc screw must engage 1.5 mm up to the flange depth, and no more. A
    longer screw bottoms out and jacks the joint apart instead of clamping it.
  - So the length follows the stack under the head, as tabulated per joint in
    [assembly.md §1](assembly.md#1-the-joint-the-servo-is-the-axle). The part
    modules' `SCREWS()` lists take it from the stack, and `check_assembly_v6`
    checks every one's engagement.
  - By length: **M3 × 5** at the leg-link horn pads 16, ankle-link tines 16,
    hip-yoke pitch horns 8, yaw carriers 8, elbow horns 8; **M3 × 6** at the
    leg-link idler pads 16, hip-yoke roll horns 8 and pitch idlers 8, shoulder
    horns 8, elbow idlers 8, head 4; **M3 × 8** at the hip-yoke roll idlers 8.
  - Buy a pack of each length.
- **The armless variant** (`ARMS=0`, not a print target) would need 84 M2.5 × 8
  flat-heads and 92 M3 disc screws (48 × M3×5, 36 × M3×6, 8 × M3×8).
- **Spares:** add about 20 % to every line, and buy the M2.5 × 8 flat-heads as a
  200-pack.

## 7. Materials

| item | qty | notes | have |
|---|---|---|---|
| PETG, 1.75 mm | 2 × 1 kg | the print set is ≈ 0.80 kg before supports and brims ([PRINT_LIST](../cad/PRINT_LIST.md)) | on hand (quantity not recorded) |
| silicone rubber sheet, **2 mm** thick: BENECREAT white silicone, 300 × 300 mm, 2 sheets ([bom-sourced](bom-sourced.md) item 16, [Amazon B08P7P69WQ](https://www.amazon.com/dp/B08P7P69WQ)) | 1 sheet cuts both soles | the soles, cut to the foot plate's outline (130 × 84 mm, R14 corners) and bonded to its flat underside; 2 mm is the design's sole (`TPU_SOLE_T`) | |
| adhesive for the soles | — | needed unless the sheet is self-adhesive (the listing shows no backing): a silicone-rubber adhesive. Plain CA and epoxy don't hold silicone; CA does over a polyolefin primer | |
| hook-and-loop strap, **15 mm** wide | 1 | the battery belt, through the pelvis belt slots (`BATT_BELT_W`) | |
| adhesive foam pads, **1 mm** thick | 2 (about 30 × 20 mm) | under the pack, one per cell ceiling, clear of the yaw servos' post holes (`BATT_PAD_T`) | |
| thread-locker, medium strength (removable) | 1 | on the M3 disc screws (the design calls for thread-locked horn screws); keep it off the printed parts | |
| retaining compound | — | §5 | |
| zip ties, 2.5 mm | 1 pack | cable dressing | |
| glue stick, isopropyl alcohol | — | glue is the release layer for PETG on the PEI plate; degrease the plate with IPA | glue ships with the printer |
| desiccant / dry box | — | keep PETG and TPU dry | |

## 8. Tools

| tool | notes | have |
|---|---|---|
| FlashForge Adventurer 5M Pro | enclosed CoreXY, 220 × 220 × 220 mm, 280 °C hotend, PEI plate, no filament lock ([PRINT_LIST](../cad/PRINT_LIST.md), Slicing) | **on hand** |
| digital calipers | | **on hand** |
| drivers for M2.5 flat-heads, M3 button heads and M2 | a slim shaft: the CAD checks a 7 mm driver cylinder over every screw, and a few screws near walls need slimmer | |
| flush cutters, deburring blade | support removal | |
| soldering iron, wire strippers, heat-shrink | power splices, the bulk capacitor, the XH pigtail | |
| lever and weights for 0.5 / 1.0 / 1.5 N·m | the #73 stiffness bench | |

Not needed: a heat-set insert tip, because the build has no inserts.

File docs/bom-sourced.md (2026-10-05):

# Bipedal Robot — Sourced Bill of Materials

*Compiled 2026-07-11. Prices in USD.*

Robot: ~34 cm, ~0.9 kg 3D-printed biped, 8× Feetech STS3215 serial-bus servos.
BOM source: [`cad/README.md`](../cad/README.md). Print settings and assembly
order also there.

> **Battery protection parts are in [`bom-supplemental.md`](bom-supplemental.md)**
> (added 2026-07-27): a balance-lead low-voltage alarm, an inline fuse, the bulk
> cap, and a watt meter. The robot works without them — that file exists because
> nothing in this BOM's power path has any protection in it, and an RC LiPo has
> none inside it either. ~$31 for the protection tier.

---

## Consolidated BOM

| # | Component | Qty | Product | Unit Price | Extended | Source | Notes |
|---|---|-----|---|---|---|---|---|
| 1 | Feetech STS3215 servo | 8 (+1–2 spares) | ST3215 Series Serial Bus Servo (**30 kg·cm@12 V version**) | $21.99 | $175.92 | [Waveshare](https://www.waveshare.com/st3215-servo.htm) | ⚠️ **Buy the 12 V version only.** The $16.99 "7.4 V" class is rated **4–7.4 V** and cannot run on 3S — the sim-recommended battery ([hardware-order.md](hardware-order.md)). The 12 V version is rated 6–12.6 V and works at either voltage. Amazon alt: [B0FGNTDV3Y](https://www.amazon.com/dp/B0FGNTDV3Y?tag=tommwhipple-20) ($29.99, 12V). |
| 2 | Waveshare ESP32 Bus Servo Driver | 1 | **Servo Driver with ESP32** (65 × 30 mm) | $24.99 | $24.99 | [Waveshare](https://www.waveshare.com/servo-driver-with-esp32.htm) / [Amazon B0CFY34BX5](https://www.amazon.com/dp/B0CFY34BX5?tag=tommwhipple-20) | ⚠️ **Corrected — the previously listed [Bus Servo Driver HAT (A)](https://www.waveshare.com/bus-servo-driver-hat-a.htm) ($18.99) is the wrong board**: it's a Raspberry-Pi HAT (65 × 57 mm — doesn't fit the tower, which is built for the 65 × 30 board) and takes 9–25 V (can't run from 2S at all). The Servo Driver with ESP32 is 6–12.6 V (2S *and* 3S direct per Waveshare docs), holes Ø2.75 on 58 × 23 — matches `cad/dimensions.py`. Schematic + user manual: [`docs/datasheets/servo-driver-esp32/`](datasheets/servo-driver-esp32/). |
| 3 | 3S LiPo battery (**decided 2026-07-11**; re-sourced 2026-07-15) | 2 | Tattu 850 mAh 11.1 V 75C 3S1P XT30 | ~$15 | ~$30 | [search](https://www.amazon.com/s?k=Tattu+850mAh+3S+75C+XT30&tag=tommwhipple-20) · [B07218SB7L](https://www.amazon.com/dp/B07218SB7L?tag=tommwhipple-20) | ✅ 60 × 30 × 23 mm, 80 g (cross-checked at 3 stockists; 80 g = the sim's `BATT_PACK_MASS`). The original Zeee (67 × 30 × 18.5) went dead on Amazon mid-project, so the bay envelope (`BATT` in `cad/dimensions.py`) is now a **superset of the whole 3S 850 XT30 class** — buy to the [spec filter](bom-by-vendor.md#notes--caveats), not an ASIN. Height is the binding axis. **11.1 V only — not 11.4 V HV** (13.05 V charged > the servo's 12.6 V ceiling). |
| 4 | Bambu Lab A1 mini 3D printer | 1 | Bambu Lab A1 mini + LED Lamp Kit | $219.00 | $219.00 | [Amazon](https://www.amazon.com/dp/B0GQMJ8QQT?tag=tommwhipple-20) | 180×180×180 mm build. AMS lite combo: [B0CRYZWJLG](https://www.amazon.com/dp/B0CRYZWJLG?tag=tommwhipple-20) ($349). Direct: [bambulab.com](https://bambulab.com). |
| 5 | PLA filament 1 kg | 1 | Bambu Lab PLA 1.75 mm 1 kg (Jade White) | $28.00 | $28.00 | [Amazon](https://www.amazon.com/dp/B0CGQYRSNT?tag=tommwhipple-20) | RFID-enabled for A1 mini auto-settings. Black: [B0CGR29R63](https://www.amazon.com/dp/B0CGR29R63?tag=tommwhipple-20) ($28.60). |
| 6 | PETG filament 1 kg | 1 | Bambu Lab PETG Translucent 1.75 mm 1 kg | $30.15 | $30.15 | [Amazon](https://www.amazon.com/dp/B0F68FKRWH?tag=tommwhipple-20) | With reusable spool. Refill-only (no spool): [B0FRQ9VX2K](https://www.amazon.com/dp/B0FRQ9VX2K?tag=tommwhipple-20) ($23.99). |
| 7 | TPU filament 500 g | 1 | Geeetech TPU 1.75 mm 500 g Shore 95A | $15.99 | $15.99 | [Amazon](https://www.amazon.com/dp/B0DG8BZL6L?tag=tommwhipple-20) | Bambu TPU is 1 kg only ($42.99, [B0GG283YLZ](https://www.amazon.com/dp/B0GG283YLZ?tag=tommwhipple-20)). |
| 8 | M3×6 button head screws | 32 | *Covered by KADRICK kit (item 15)* | — | — | — | Kit includes M3×6/8/10/12/16/20/25/30 mm. |
| 9 | M3×6 button head (idlers, no washer) 24 + M3×8 (hip-roll idler) 8 |  32 | *Covered by KADRICK kit (item 15)* | — | — | — | Kit includes nuts & washers. |
| 10 | M3×10 button head screws | 16 | *Covered by KADRICK kit (item 15)* | — | — | — | Kit includes M3×6/8/10/12/16/20/25/30 mm. |
| 11 | M3×8 self-tapping screws | 52 | 100 pc M3×8 mm Self-Tapping SS, Flat Head Hex | $8.28 | $8.28 | [Amazon](https://www.amazon.com/dp/B0F9XYX9BQ?tag=tommwhipple-20) | 100 pcs (52 needed). Includes drive bit. Alt: [520pc assortment](https://www.amazon.com/dp/B0BPM8J5F5?tag=tommwhipple-20) ($7.99). |
| 12 | M3 heat-set inserts (Ø4.6×4–6 mm) | 12 | *Covered by KADRICK kit (item 15)* | — | — | — | Kit includes brass heat-set inserts. |
| 13 | M5×20 GoPro thumbscrew | 1 | M5 Handle Thumb Screws (pair, GoPro) | $7.22 | $7.22 | [Amazon](https://www.amazon.com/dp/B0BCJRFCLX?tag=tommwhipple-20) | Pair; only 1 needed. Stainless, GoPro Hero 4–13. |
| 14 | M2.5×8 self-tapping screws | 4 | uxcell 50 pc M2.5×8 mm Self-Tapping | $8.07 | $8.07 | [Amazon](https://www.amazon.com/dp/B01KXTTSCI?tag=tommwhipple-20) | 50 pcs (4 needed). 304 SS. |
| 15 | M3 screw + heat-set insert kit | 1 | KADRICK 420 pcs M3 Heat Set Inserts Kit | $15.99 | $15.99 | [Amazon](https://www.amazon.com/dp/B0GYRQG7F2?tag=tommwhipple-20) | **Covers items 8, 9, 10, 12.** M3×6–30 mm socket cap screws, brass inserts, nuts, washers, installation tip, hex key. |
| 16 | TPU sheet 2 mm | 2 | BENECREAT 2-pc Silicone Rubber Sheet 2 mm | $15.59 | $15.59 | [Amazon](https://www.amazon.com/dp/B08P7P69WQ?tag=tommwhipple-20) | 2 sheets. Cut to 90×46 mm for foot pads. Silicone rubber ≈ TPU functionally. |
| 17 | Zip ties 2.5 mm | ~10 | Zip Ties 2.5 mm×200 mm 100 pc | $3.99 | $3.99 | [Amazon](https://www.amazon.com/dp/B0GR52PRHF?tag=tommwhipple-20) | 100 pcs (~10 needed). Black nylon, 30 lb. |
| 18 | 9-DOF IMU | 1 | Teyleten Robot GY-BNO085 9DOF AHRS module | $20.99 | $20.99 | [Amazon B0CL26J81F](https://www.amazon.com/dp/B0CL26J81F?tag=tommwhipple-20) | **Actual part ordered** (2026-07-16). BNO085 chip (Hillcrest Labs CEVA SH-2 fusion on-chip). Same IC as the planned Adafruit #4754 breakout but ~$4 cheaper; I2C/SPI/UART/UART-RVC interfaces. Datasheet: [`docs/datasheets/BNO08X-datasheet.pdf`](datasheets/BNO08X-datasheet.pdf) (Hillcrest Labs BNO08X v1.16, 59pp). Note: non-STEMMA breakout — pin headers instead of JST-SH jack, so item 21 cable may need swapping for jumper wires. |
| 19 | Servo bus extension leads, 3-pin ≥200 mm | 2 (+2 spares) | Feetech/Waveshare 3-pin bus servo cable, 200–300 mm | ~$1–2 | ~$8 | [search](https://www.amazon.com/s?k=feetech+3+pin+servo+cable+200mm&tag=tommwhipple-20) · [Waveshare](https://www.waveshare.com/product/robotics/accessories.htm) | For the **hip-roll → hip-pitch** hop (one per leg): worst-pose routed path is **170 mm** (measured in `cad/dress.py` across the full ROM incl. slack loop), so the 150 mm leads that ship with the servos are too short *there and only there*. ≥200 mm gives ~18 % flex margin; if only 300 mm is stocked, zip-tie the excess at the thigh raceway anchors. Every other hop fits a stock 150 mm lead (see [wiring.md](wiring.md)). |
| 20 | XT30 pigtail + inline switch + heat-shrink | 1 set | XT30 pigtail (mates the pack lead) → inline switch → bare ends into the board's screw terminal | ~$10 | ~$10 | [search](https://www.amazon.com/s?k=xt30+pigtail+connector+inline+switch&tag=tommwhipple-20) | Battery → power switch → driver-board screw terminal. Routed run is only ~30 mm, so any short pigtail works; 20 AWG or thicker (bus transient budget ~10 A). |
| 21 | IMU cable, JST-SH 4-pin → male jumpers | 1 | Adafruit STEMMA QT / Qwiic to male headers, 150 mm | $0.95 | $0.95 | [Adafruit 4209](https://www.adafruit.com/product/4209) | BNO085 → ESP32 GPIO 21/22 + 3V3/GND. The driver board has no STEMMA jack, so this (or 4 soldered wires) bridges it. IMU mounts on the deck next to the board — 150 mm is ample. |
| 22 | **General Driver swap:** power pigtail, JST XH 2-pin | 1 (+1 spare) | Pre-crimped JST-XH 2.54 mm 2-pin female pigtail (housing XHP-2 + SXH contacts), 22 AWG, ≥100 mm | ~$1–2 | ~$6 (sold in packs) | [search](https://www.amazon.com/s?k=jst+xh+2.54+2+pin+connector+pigtail+female+22awg&tag=tommwhipple-20) | The General Driver's power inlet is **XH2.54, not a barrel jack** ([official docs index](datasheets/general-driver/README.md), incl. the manufacturer's connector diagram). Splice onto the item-20 switch lead (solder + heat-shrink; XH crimps take **max 22 AWG**, so the 20 AWG lead can't go into the housing directly). ⚠️ XH contact is rated **3 A**; the board's own bus-servo path is FAQ-limited to **5 A continuous ("up to 5 ST3215s, not stalled simultaneously")** — bimo runs 8 with a ~10 A transient budget. Resolve before the swap goes on hardware (options: accept brown-out risk with per-leg current shaping, or bypass the XH inlet and solder to the pads). ⚠️ Verify polarity against the board silkscreen before first plug — pigtail wire colors are not standardized. Not a 2S "balance lead" (that's XH **3**-pin). |

---

## Cost Summary

| Category | Estimated Cost |
|---|---|
| Electronics (8 servos + driver + battery + IMU) | ~$245 |
| Servo spares (1–2 recommended) | $22–44 |
| 3D printer | $219.00 |
| Filament (PLA + PETG + TPU) | $74.14 |
| Hardware (screws, inserts, thumbscrew, sheet, zip ties) | $59.14 |
| Wiring (bus extensions, XT30 pigtail + switch, IMU cable) | ~$19 |
| **Total Estimated** | **~$640–660** |

**Not yet on this list** (from [hardware-order.md](hardware-order.md)): 2S–3S
balance charger (~$30, skip if owned) and a USB-C **data** cable for
flashing/debug (skip if owned). Also note items 7 and 16 are redundant — foot pads are *printed* TPU
(item 7); the silicone sheet (item 16, $15.59) can be dropped unless you want
a fallback. The KADRICK kit is socket-cap, not button-head — check head
clearance at the idler screws before relying on it there.

### Servo cost optimization — ~~retracted~~

~~Using Waveshare 7.4V servos ($16.99 × 8 = $135.92) saves ~$40.~~
**Don't**: the 7.4 V class is rated **4–7.4 V only** (per Waveshare's own
listing), so it permanently forecloses the 3S option that the sim gauntlet
recommends (2.72 s vs 4.36 s dash; 16/16 vs 12/16 with the GoPro on rough
ground — see [hardware-order.md](hardware-order.md)). The $40 delta buys the
ability to choose the battery later. Buy 8 + 1–2 spares of the 12 V version.

---

## Notes

- **Items 8, 9, 10, 12 consolidated** into the KADRICK 420 pcs kit ($15.99), which
  includes M3×6–30 mm screws, brass heat-set inserts, nuts, washers, installation
  tip, and hex key. This single kit covers all M3 button head screws, M3 washers,
  and M3 heat-set inserts in the BOM.
- **Battery dimensions** — must verify the specific battery fits ≤ 75×35×16 mm
  before purchase. RC car batteries vary; check product dimensions carefully.
- **TPU sheet** — true TPU sheet was not found on Amazon. Silicone rubber sheet
  (2 mm) is the closest functional equivalent for grip pads / foot soles.
- **Bambu Lab store** (bambulab.com) was blocked by Cloudflare; Amazon prices
  match expected retail ($219 for A1 mini).
- **Waveshare direct** offers the best prices on the two most expensive
  electronic components: ST3215 servos ($16.99–$21.99 vs $24.35+ on Amazon) and
  the ESP32 driver HAT ($18.99 vs $24.99 on Amazon). Shipping from Waveshare
  may take longer than Amazon Prime — check lead time before ordering.
- **DigiKey** was behind Cloudflare bot detection and could not be browsed.
  DigiKey does not appear to carry Feetech servos or Waveshare boards (they are
  hobby robotics parts, not standard electronic components). DigiKey is better
  suited for the fasteners and hardware — search for "M3 button head screw" or
  "heat set insert" at [digikey.com](https://www.digikey.com) directly.
- All prices captured July 11, 2026. Prices and availability subject to change.

---

## Open BOM Questions (from cad/README.md)

- **Servo case thread**: M3 self-tap vs tap vs M4 — measure a real case.
- **Idler screw length**: ~~M3×8 + washer assumes 3.35 mm thread depth~~
  **RESOLVED 2026-07-30** — bench + vendor STEP: the bolt circle taps a 2.1 mm
  flange, not the 3.35 mm body. Re-sized to M3×6 (M3×8 at the hip-roll idler),
  no washers. Asserted in `cad/check_assembly.py`. Original note: confirm
  screws don't bottom against the gear.
- **Driver board**: exact model + hole pattern (`BOARD_HOLES` in `dimensions.py`)
  — confirm component heights and battery clearance.
- **GoPro fit**: measure your MAX's finger thickness — slots are 3.2 mm.
- **Cable service loops**: routed worst-pose lengths measured in `cad/dress.py`
  (2026-07-16) — hip-roll→hip-pitch 170 mm (**needs the item-19 extensions**),
  hip-pitch→knee 111 mm, knee→ankle 82 mm, board→hip-roll 33 mm; all but the
  first fit the stock 150 mm leads with ≥25 % slack. Confirm the shipped lead
  length really is 150 mm when the servos arrive.
- **Foot pad material**: TPU sheet vs printed TPU vs adhesive rubber; friction
  should roughly match sim (μ ≈ 1.0).

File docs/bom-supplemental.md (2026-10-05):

# Supplemental BOM — battery protection & power bench

*Compiled 2026-07-27. Prices in USD.*

Everything here came out of the "do we need to guard against overdraw?"
question. The reasoning behind each line is in
[wiring.md § Battery protection](wiring.md#battery-protection) — this file is
just the shopping list. It is **supplemental to** [bom-sourced.md](bom-sourced.md):
the robot is complete and functional without any of it.

> **Prices are indicative, not captured.** These are commodity RC parts whose
> listings churn constantly, so the links are *search queries* rather than
> ASINs — the same pattern the main BOM uses for its generic rows. Check price
> and stock in a browser; a cached product title is not a live listing.

---

## Buy first — the one real gap

| # | Component | Qty | Spec that matters | Est. | Source |
|---|---|-----|---|---|---|
| S1 | LiPo low-voltage alarm / buzzer | 1–2 | **1S–8S**, plugs onto the pack's **JST-XH balance lead**, adjustable or 3.3 V/cell alarm point, per-cell display | ~$7 (usually sold in 2–4 packs) | [search](https://www.amazon.com/s?k=lipo+low+voltage+alarm+buzzer+1s-8s+balance&tag=tommwhipple-20) |

This is the highest-value part on the page and it costs about as much as a
coffee. It is the **only** protection that is independent of the firmware: it
still sounds if the ESP32 hangs, if the control loop wedges, or if the servo
bus drops — and the bus dropping is precisely how the firmware guard goes
blind, because the robot's only voltage sense is the servos' register 62
(no ADC on the driver board).

It also monitors **per cell**, which pack voltage fundamentally cannot. One
weak cell sitting at 2.9 V while the other two are healthy still reads ~10.6 V
at the pack — a number the firmware guard calls fine, because from where it
sits, it is.

Buy 2 if you want one living on each of the two packs; buy 1 and move it if you
don't mind the swap step.

**Fit note:** it hangs off the balance lead, which is the *unused* connector on
the pack — the XT30 carries the load. Check it clears the tower window when the
pack is seated, or let it sit outside the bay on its lead during bring-up.

---

## Worth it — the short-circuit case

| # | Component | Qty | Spec that matters | Est. | Source |
|---|---|-----|---|---|---|
| S2 | Inline blade-fuse holder, **mini (ATM)** | 1 | 16–18 AWG pigtail, waterproof/heat-shrink body | ~$8 (2-pack) | [search](https://www.amazon.com/s?k=inline+mini+blade+fuse+holder+16+awg&tag=tommwhipple-20) |
| S3 | Mini blade fuses, assorted | 1 pack | Need **10 A and 15 A**; start at 12–15 A | ~$7 | [search](https://www.amazon.com/s?k=mini+blade+fuse+assortment+10a+15a&tag=tommwhipple-20) |

Nothing in the power path has a fuse, polyfuse, e-fuse, or protection FET —
confirmed from Waveshare's schematic. Operating current is a non-issue (1.4 A
RMS, 6.8 A millisecond peaks, against a 5 A jack rating). The case this covers
is a **dead short**, where an 850 mAh 75C pack can deliver ~60 A into a pinched
or chafed lead. A robot that falls over repeatedly, with servo leads under
strain and a pack that swaps in and out of a window, is where that happens.

**Sizing:** 15 A is the safe first choice — comfortably above the 6.8 A
sim-derived peak, well below a short. Drop to 10 A only after the bench
measurement (S5) confirms the real peak, otherwise you will nuisance-blow on a
hard landing and learn nothing.

**Integration caveat, stated honestly:** the routed pigtail run is only ~30 mm
(wiring.md), and an inline holder plus its leads is more like 40–60 mm. This
does *not* drop in — expect either a longer pigtail with the fuse body coiled
into the y-pocket beside the XT30, or the holder sitting proud of the bay.
Decide where it lives before ordering the pigtail, and re-check the
battery-swap path still works with it in place.

**Do not substitute a polyfuse/PPTC.** Its trip time is seconds and its series
resistance is meaningful at these currents — wrong instrument for a dead short,
and it would sag the rail the rest of the time.

---

## Already recommended in wiring.md

| # | Component | Qty | Spec that matters | Est. | Source |
|---|---|-----|---|---|---|
| S4 | Low-ESR electrolytic capacitor | 1–2 | **470–1000 µF, ≥ 25 V**, low-ESR / "low impedance", 105 °C | ~$9 (assortment) | [search](https://www.amazon.com/s?k=470uf+25v+low+esr+electrolytic+capacitor&tag=tommwhipple-20) |

Across servo V+/GND at the board. The `6-12V` net carries only 10 µF + 0.1 µF
of local bulk, so a 6.8 A step is sourced all the way through the pack leads
and the barrel jack; a bulk cap sources it locally, cutting rail sag and the
transient the jack actually sees. It also makes the firmware guard less twitchy,
since less sag means fewer excursions toward the trip line.

**25 V, not 16 V.** A fully charged 3S is 12.6 V; standard derating practice
wants roughly double, and 16 V parts leave nothing. **Polarity matters** —
electrolytics fail loudly when reversed. This is a soldering job onto the
pigtail or a spare header, not a plug-in part.

---

## Optional — closes an open question

| # | Component | Qty | Spec that matters | Est. | Source |
|---|---|-----|---|---|---|
| S5 | Inline RC watt meter / power analyzer | 1 | ≥ 60 A, **XT30 or XT60 with adapters**, shows peak A | ~$20 | [search](https://www.amazon.com/s?k=rc+watt+meter+power+analyzer+60a+xt60&tag=tommwhipple-20) |

wiring.md's current table is **sim-derived, not measured**, and explicitly asks
for a bench check: *"Bench-verify the peak with an inline shunt or clamp during
the first walks."* This is the cheapest way to do that. It also settles the
fuse sizing above (S2/S3) with a number instead of a margin, and gives a real
mAh-consumed figure per walk — which is the honest input to any future
runtime estimate.

Not required for safety; it is the instrument that turns three estimates in
this repo into measurements.

---

## Also worth having (generic LiPo hygiene)

| # | Component | Qty | Spec that matters | Est. | Source |
|---|---|-----|---|---|---|
| S6 | LiPo charge/storage bag or case | 1 | Fits a 60 × 30 × 23 mm pack with room to spare | ~$12 | [search](https://www.amazon.com/s?k=lipo+safe+charging+bag&tag=tommwhipple-20) |

Standard practice for any LiPo, independent of this robot. Worth pairing with a
habit rather than a part: **storage-charge to ~3.8 V/cell (11.4 V) if a pack
will sit for more than a few days.** Leaving a pack full or flat is what kills
packs that never see a fault. A smart charger has a storage mode; use it.

---

## Totals

| Tier | Lines | Est. |
|---|---|---|
| Buy first | S1 | ~$7 |
| Worth it | S2, S3 | ~$15 |
| wiring.md recommendation | S4 | ~$9 |
| Optional instrument | S5 | ~$20 |
| LiPo hygiene | S6 | ~$12 |
| **All of it** | | **~$63** |

The protection story is ~$31 (S1–S4). The rest is instrumentation and hygiene.

## What is deliberately NOT here

- **A BMS / protection board.** These exist for LiPo packs but are sized for
  low-current cells; a board that passes 6.8 A peaks without sagging costs and
  weighs more than the problem justifies, on a 0.9 kg robot where mass is the
  binding constraint. The firmware guard plus the balance-lead alarm covers the
  same failure at ~10 g.
- **A current sensor (INA219 etc.).** The driver board has no sense resistor
  and no free path to add one without cutting the servo V+ net. S5 does the same
  job on the bench, which is where the question actually lives.
- **An anti-spark connector.** At 3S and this capacitance, XT30 connection arc
  is negligible. This matters at 6S and multi-thousand-µF, not here.

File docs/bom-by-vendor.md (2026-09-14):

# Bipedal Robot — Bill of Materials (grouped by vendor)

*Compiled from [`bom-sourced.md`](bom-sourced.md). Prices in USD, captured
2026-07-11. Prices and availability subject to
change.*

Robot: ~34 cm, ~0.9 kg 3D-printed biped, 8× Feetech STS3215 serial-bus servos.

> **The 3D printer and filament are now a separate one-time order** —
> see [`printer-order.md`](printer-order.md). This file is robot parts only.

---

## Waveshare

| Component | Qty | Product | Unit | Extended | Link |
| --- | --- | --- | --- | --- | --- |
| Feetech STS3215 servo  | 8 (+1–2 spares) | ST3215 Serial Bus Servo — **30 kg·cm @ 12 V version** (rated 6–12.6 V; buy this, *not* the $16.99 4–7.4 V version) | $21.99 | $175.92 | https://www.waveshare.com/st3215-servo.htm |
| ESP32 Bus Servo Driver | 1 | Servo Driver with ESP32 (65 × 30 mm, 6–12.6 V — 2S & 3S direct) | $24.99 | $24.99 | [waveshare.com](https://www.waveshare.com/servo-driver-with-esp32.htm) |
| **Waveshare subtotal** | | | | **$200.91** | |

Best direct prices on the two most expensive electronic parts. Shipping may be
slower than Amazon Prime — check lead time. Amazon alternates: servo
[B0FGNTDV3Y](https://www.amazon.com/dp/B0FGNTDV3Y?tag=tommwhipple-20) ($29.99, 12 V), driver
[B0CFY34BX5](https://www.amazon.com/dp/B0CFY34BX5?tag=tommwhipple-20) ($24.99).

---

## Amazon

| Component | Qty | Product | Unit | Extended | Link |
| --- | --- | --- | --- | --- | --- |
| 3S LiPo battery | 2 | Tattu 850 mAh 11.1 V 75C 3S1P XT30 (60 × 30 × 23 mm, 80 g) — or any pack meeting the spec filter below | ~$15 | ~$30.00 | [search](https://www.amazon.com/s?k=Tattu+850mAh+3S+75C+XT30&tag=tommwhipple-20) · ASIN [B07218SB7L](https://www.amazon.com/dp/B07218SB7L?tag=tommwhipple-20) |
| M3 screw + heat-set insert kit | 1 | KADRICK 420 pc M3 kit — covers M3×6–30 screws, brass inserts, nuts, washers | $15.99 | $15.99 | [B0GYRQG7F2](https://www.amazon.com/dp/B0GYRQG7F2?tag=tommwhipple-20) |
| M3×8 self-tapping screws | 52 (100 pc)  | M3×8 Self-Tapping SS, flat head hex (incl. drive bit) | $8.28  | $8.28 | [B0F9XYX9BQ](https://www.amazon.com/dp/B0F9XYX9BQ?tag=tommwhipple-20) |
| M2.5×8 self-tapping screws | 4 (50 pc) | uxcell M2.5×8 self-tapping, 304 SS | $8.07  | $8.07 | [B01KXTTSCI](https://www.amazon.com/dp/B01KXTTSCI?tag=tommwhipple-20) |
| M5×20 GoPro thumbscrew | 1 (pair) | M5 handle thumb screws, stainless, GoPro Hero 4–13 | $7.22  | $7.22 | [B0BCJRFCLX](https://www.amazon.com/dp/B0BCJRFCLX?tag=tommwhipple-20) |
| Sole pad sheet 1/16" | 1 (2-pack) | Self-adhesive silicone rubber sheet, 2× 6"×6" — cut two 106 × 46 mm pads (one sheet does both feet; 2nd sheet = spares) | — | — | [B0FJ8TBMQK](https://www.amazon.com/dp/B0FJ8TBMQK?tag=tommwhipple-20) |
| Zip ties 2.5 mm | ~10 (100 pc) | 2.5 × 200 mm black nylon, 30 lb | $3.99  | $3.99 | [B0GR52PRHF](https://www.amazon.com/dp/B0GR52PRHF?tag=tommwhipple-20) |
| 9-DOF IMU | 1 | Teyleten Robot GY-BNO085 9DOF AHRS (BNO085 chip, CEVA SH-2 fusion — actual part ordered 2026-07-16) | $20.99 | $20.99 | [B0CL26J81F](https://www.amazon.com/dp/B0CL26J81F?tag=tommwhipple-20) |
| **Amazon subtotal** | | | | **~$110.13** | |

---

## ~~Adafruit~~ → moved to Amazon

The IMU was originally planned as an Adafruit BNO085 breakout (#4754, $24.95).
Actual order: Teyleten Robot GY-BNO085 via Amazon [B0CL26J81F](https://www.amazon.com/dp/B0CL26J81F?tag=tommwhipple-20)
($20.99) — same BNO085 IC, ~$4 cheaper. Datasheet in
[`docs/datasheets/BNO08X-datasheet.pdf`](datasheets/BNO08X-datasheet.pdf).

Cheap spare/alt: MPU-6050 "GY-521" (~$5, needs a filter in firmware).

---

## Vendor totals

| Vendor | Extended  |
| --- | --- |
| Waveshare | $200.91 |
| Amazon | ~$110.13  |
| **Robot total** | **~$311** |

Servo spares (1–2 × $21.99) are the main swing item. The 3D printer + filament +
start-up consumables (~$530, FlashForge 5M Pro) is a separate one-time order —
see [`printer-order.md`](printer-order.md).
All-in from zero (robot + printer order): **~$845**.

---

## Notes & caveats

- **Servo voltage class is order-critical.** Buy the 12 V-class ST3215
  (6–12.6 V). The cheaper $16.99 "7.4 V" version is rated 4–7.4 V and forecloses
  the sim-recommended 3S battery.

- **Driver board.** Use the "Servo Driver with ESP32" (65 × 30 mm), *not* the
  Bus Servo Driver HAT (A) — that Pi HAT is the wrong size and 9–25 V input.
  Waveshare also sells PCA9685-based boards that drive *PWM* servos — those
  cannot talk to ST/SC bus servos at all. On Amazon the same board is listed as
  [B0CFY34BX5](https://www.amazon.com/dp/B0CFY34BX5?tag=tommwhipple-20),
  [B0F5W67S56](https://www.amazon.com/dp/B0F5W67S56?tag=tommwhipple-20), and
  [B09SZ41RJW](https://www.amazon.com/dp/B09SZ41RJW?tag=tommwhipple-20) — buy whichever is cheapest
  and in stock; prefer a title that states "6~12V" and "SC, ST Series".

- **Battery: buy to the spec filter, not to an ASIN.** The bay was originally cut
  for the Zeee 3S 850 (67 × 30 × 18.5, 74 g), which went unavailable — and every
  other 3S 850 is stubbier but *taller*, so nothing dropped in. The bay is now
  sized (`BATT` in `cad/dimensions.py`) to swallow the whole class. **Any pack
  meeting all four of these fits, no CAD change:**
  
  |           | requirement                      | why                                                       |
  | --------- | -------------------------------- | --------------------------------------------------------- |
  | chemistry | **3S, 11.1 V** — *not* 11.4 V HV | LiHV charges to 13.05 V, over the ST3215's 12.6 V ceiling |
  | connector | **XT30**                         | not JST / EC5 / XT60; the pigtail assumes it              |
  | height    | **≤ 26.5 mm**                    | binding axis — 3.5 mm board clearance above               |
  | footprint | **≤ 68 (L) × 31 mm (W)**         | bay envelope; L runs laterally                            |
  
  BOM pick is the **Tattu 850 mAh 75C** (60 × 30 × 23 mm, 80 g) — specs
  cross-checked against three independent stockists, and its 80 g is the mass
  the sim models (`BATT_PACK_MASS`). Ovonic 80C (60 × 30 × 24, 76 g) and CNHL
  70C (62 × 30 × 25, ~80 g) also fit. **Amazon ASINs for these packs churn**
  (the Zeee's went dead mid-project) — prefer the search link in the table and
  apply the filter above. Short packs (59–62 mm) leave up to 8 mm of *lateral*
  slop; shim it (see `DESIGN.md`, "Battery bay widened") — the sim assumes the
  pack is centered and cannot represent it moving.

- **Fastener consolidation.** The KADRICK kit covers all M3 button-head screws,
  washers, and heat-set inserts (originally 4 separate line items). It is
  socket-cap, not button-head — check head clearance at the idler screws.

- **Foot pads: cut, not printed.** Decision 2026-07-15 — all structural parts
  print in PETG, and the sole pads are cut from the self-adhesive 1/16"
  silicone sheet above (106 × 46 mm each) and stuck to the flat sole. No TPU
  filament needed for the pads.

- **Not yet sourced / not vendor-grouped here:** 2S–3S balance charger (~$30,
  skip if owned), XT30 pigtail + heat-shrink + inline power switch (~$10),
  2 longer servo extension leads (hip→board), battery belt + pull ribbon (~$5
  or scrap velcro). See [hardware-order.md](hardware-order.md).

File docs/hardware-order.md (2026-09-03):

# Hardware order checklist

*Status 2026-07-11. Goal: everything needed for the first physical build.
Sim validation state: gaits verified under real STS3215 torque limits at both
battery voltages; sub-step control-latency validated and hardened (DESIGN.md
§sub-step latency) — nothing on this parts list changed.*

## ✅ DECIDED 2026-07-11: 3S (11.1 V)

The gauntlet numbers that drove it (2 m dash median **2.72 s** vs 4.36 s;
GoPro + rough ground **16/16** vs 12/16), and what the decision changed:
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

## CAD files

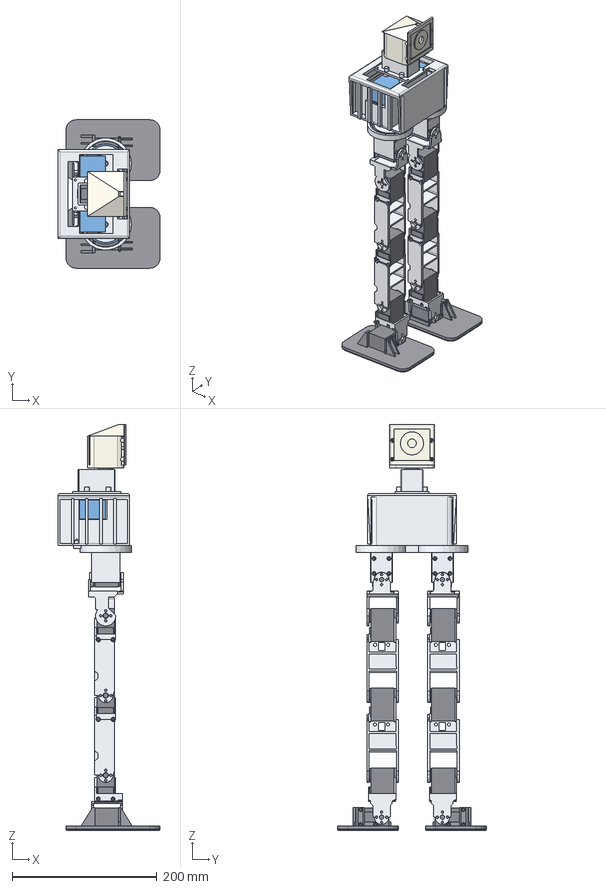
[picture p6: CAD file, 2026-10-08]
cad/v6/step/assembly_v6.step
140.9 x 205.0 x 560.5 mm
pelvis_v7
yaw_bearing_housing
pack_mock
pi4_mock
gd_mock
servo_neck
neck_floor
neck_collar
head
servo_hip_yaw_L
yaw_carrier_L
bearing_inner_L
bearing_outer_L
servo_hip_roll_L
hip_yoke_L
servo_hip_pitch_L
thigh_L
servo_knee_L
shin_L
servo_ankle_pitch_L
ankle_link_L
servo_ankle_roll_L
foot_L
sole_L
servo_hip_yaw_R
yaw_carrier_R
bearing_inner_R
bearing_outer_R
servo_hip_roll_R
hip_yoke_R
servo_hip_pitch_R
thigh_R
servo_knee_R
shin_R
servo_ankle_pitch_R
ankle_link_R
servo_ankle_roll_R
foot_R
sole_R

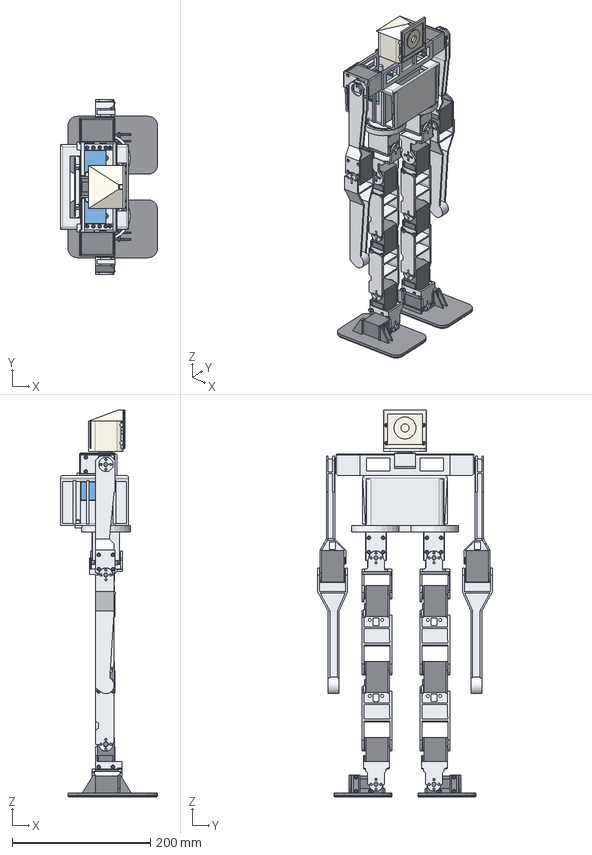
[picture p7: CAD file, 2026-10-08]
cad/v6/step/assembly_v6_arms.step
140.9 x 253.6 x 560.5 mm
pelvis_v7
yaw_bearing_housing
pack_mock
pi4_mock
gd_mock
servo_neck
neck_floor
shoulder_girdle_v6
head
servo_hip_yaw_L
yaw_carrier_L
bearing_inner_L
bearing_outer_L
servo_hip_roll_L
hip_yoke_L
servo_hip_pitch_L
thigh_L
servo_knee_L
shin_L
servo_ankle_pitch_L
ankle_link_L
servo_ankle_roll_L
foot_L
sole_L
servo_hip_yaw_R
yaw_carrier_R
bearing_inner_R
bearing_outer_R
servo_hip_roll_R
hip_yoke_R
servo_hip_pitch_R
thigh_R
servo_knee_R
shin_R
servo_ankle_pitch_R
ankle_link_R
servo_ankle_roll_R
foot_R
sole_R
servo_shoulder_L
arm_upper_L
servo_elbow_L
arm_fore_L
servo_shoulder_R
arm_upper_R
servo_elbow_R
arm_fore_R

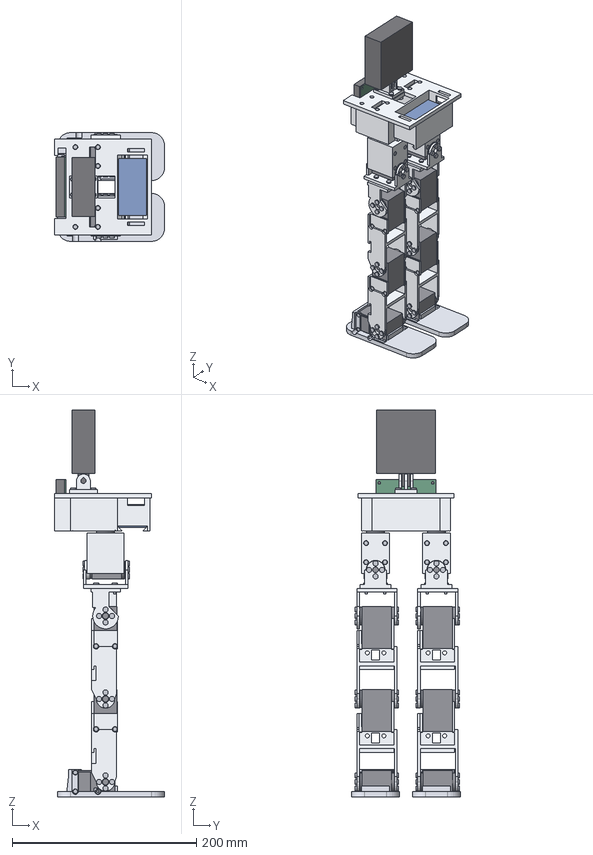
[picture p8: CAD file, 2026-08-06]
cad/step/assembly.step
119.4 x 118.0 x 419.8 mm
pelvis
gopro_base
camera_gopro_max_mock
battery_3s_mock
board_pcb_mock
board_parts_mock
screws_deck
screws_driver_board
screws_gopro
servo_hip_yaw x 2
yaw_carrier x 2
servo_hip_roll x 2
yoke_roll x 2
yoke_pitch x 2
servo_hip_pitch x 2
link_thigh x 2
servo_knee x 2
link_shin x 2
servo_ankle x 2
foot x 2
screws_yaw_stack x 2
screws_hip_roll x 2
screws_flange x 2
screws_hip_pitch x 2
screws_thigh_grip x 2
screws_knee x 2
screws_shin_grip x 2
screws_ankle x 2
screws_foot x 2

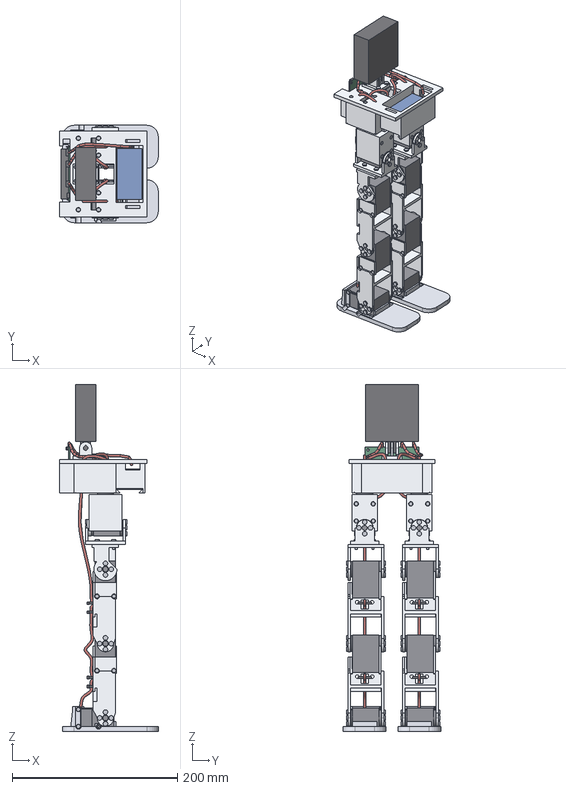
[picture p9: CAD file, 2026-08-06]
cad/step/assembly_full.step
119.4 x 118.0 x 419.8 mm
pelvis
gopro_base
camera_gopro_max_mock
battery_3s_mock
board_pcb_mock
board_parts_mock
pigtail_xt30
cable_board_L
cable_board_R
cable_yaw_L
cable_yaw_R
screws_deck
screws_board
screws_gopro
servo_hip_yaw x 2
yaw_carrier x 2
servo_hip_roll x 2
yoke_roll x 2
yoke_pitch x 2
servo_hip_pitch x 2
link_thigh x 2
servo_knee x 2
link_shin x 2
servo_ankle x 2
foot x 2
screws_yaw_stack x 2
screws_hip_roll x 2
screws_flange x 2
screws_hip_pitch x 2
screws_thigh_grip x 2
screws_knee x 2
screws_shin_grip x 2
screws_ankle x 2
screws_foot x 2
cable_hip x 2
cable_thigh x 2
cable_shin x 2
ties_thigh x 2
ties_shin x 2

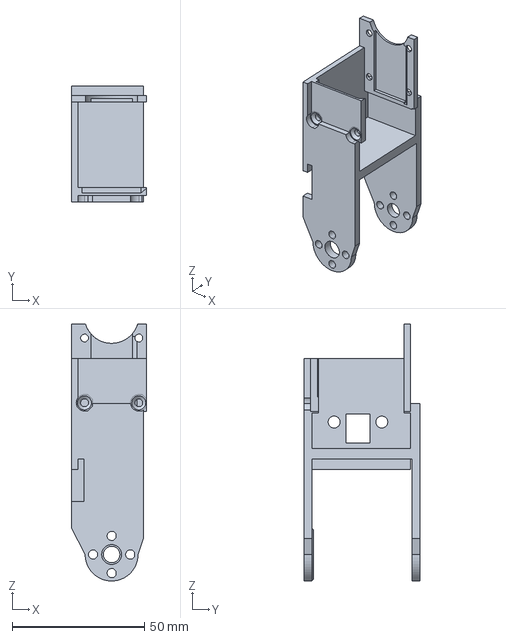
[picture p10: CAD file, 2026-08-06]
cad/step/leg_link.step
28.4 x 43.9 x 97.0 mm

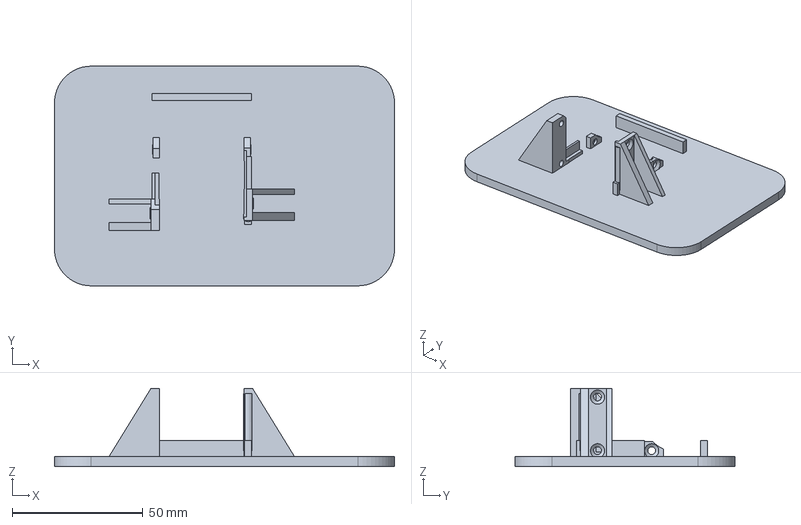
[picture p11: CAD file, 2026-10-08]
cad/v6/step/foot_R.step
130.0 x 84.0 x 30.0 mm

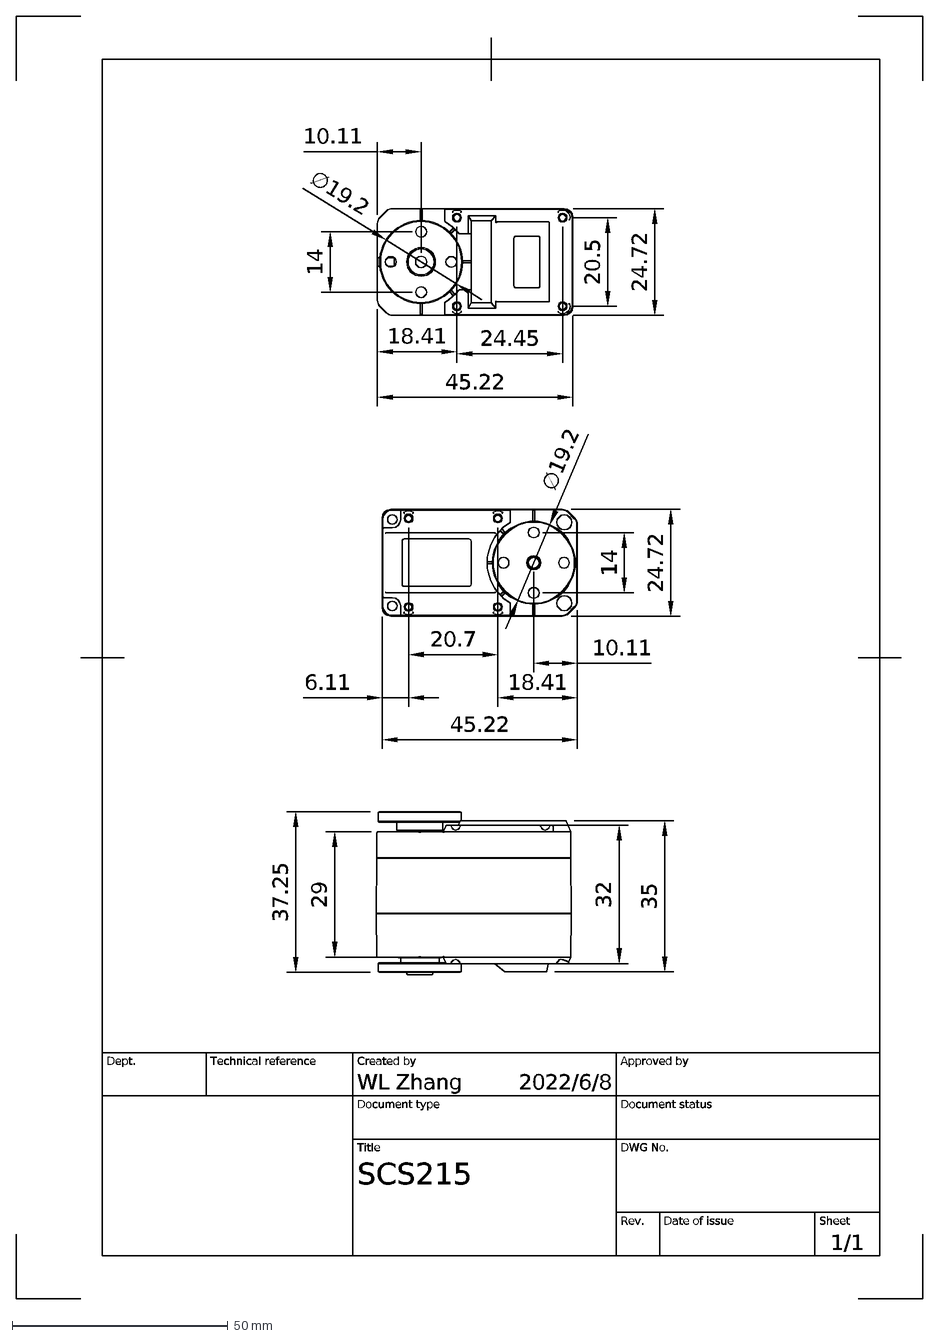
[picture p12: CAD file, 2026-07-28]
docs/datasheets/st3215/ST3215-outline-drawing.dxf
2022/6/8
1/1
SCS215
WL Zhang
Dept.
Technical reference
Created by
Approved by
Document type
Document status
Title
DWG No.
Rev.
Date of issue
Sheet
24.45
18.41
10.11
20.5
24.72
45.22
37.25
20.7
6.11
∅19.2
14
32
35
29

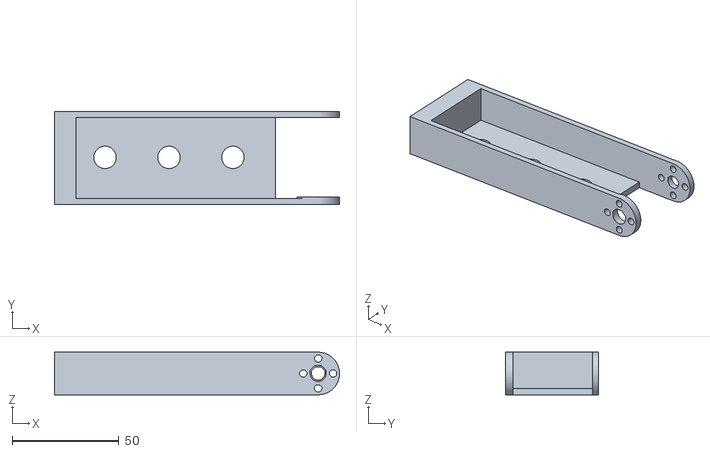
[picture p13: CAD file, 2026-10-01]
experiments/plan-b-bench/stl/plan_b_v3_fork.stl
133.7 x 43.8 x 20.0

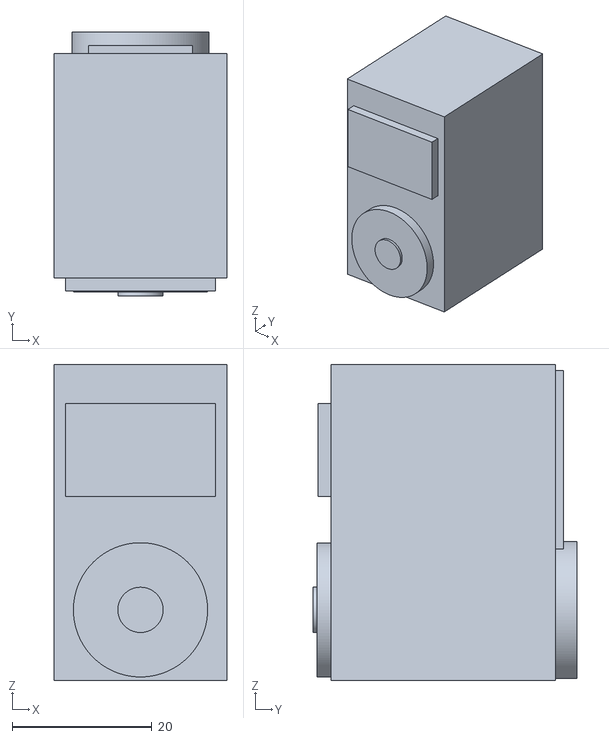
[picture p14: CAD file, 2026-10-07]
sim/meshes/v6/servo_elbow_L.stl
24.7 x 37.8 x 45.2

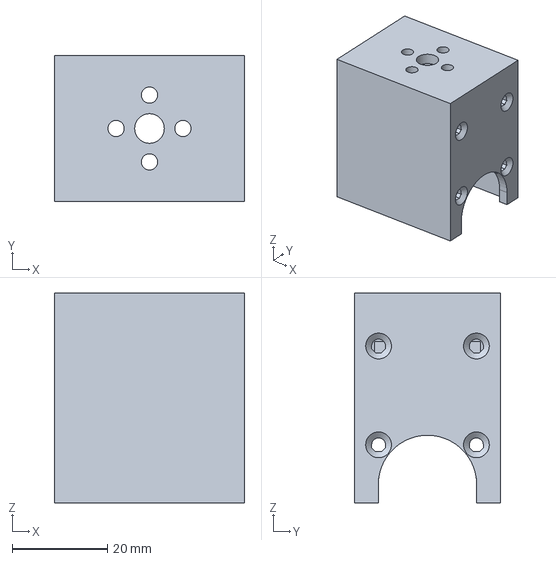
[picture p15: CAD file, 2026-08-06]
cad/step/yaw_carrier_print.step
39.9 x 30.5 x 44.0 mm

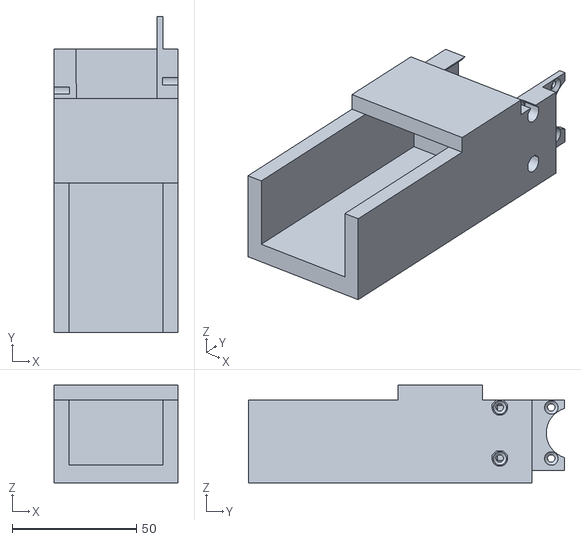
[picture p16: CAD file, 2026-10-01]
experiments/plan-b-bench/stl/plan_b_v3_bracket.stl
49.7 x 127.0 x 39.2

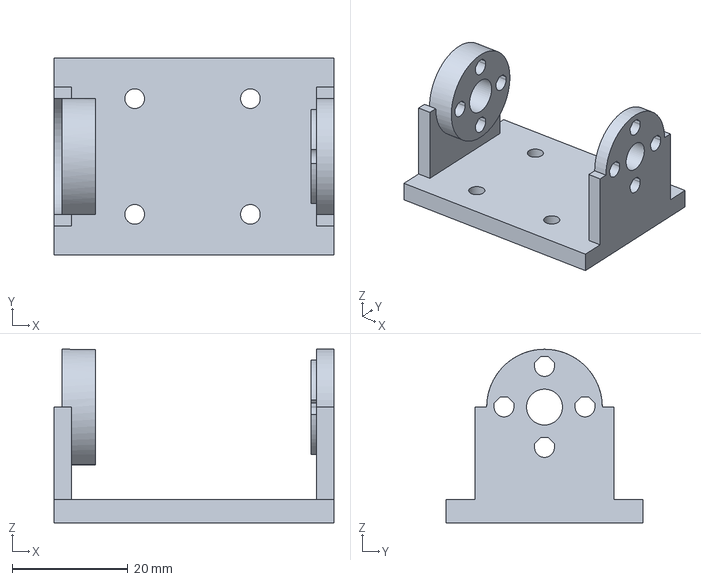
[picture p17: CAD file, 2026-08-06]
cad/step/yoke_roll.step
48.4 x 34.0 x 30.0 mm

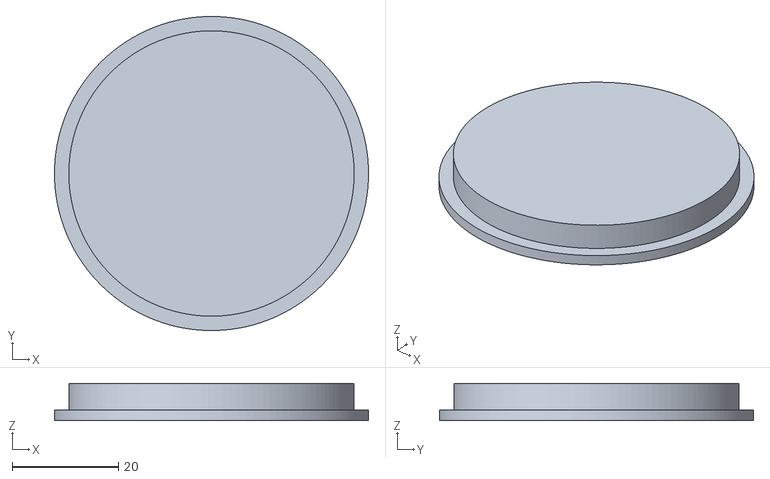
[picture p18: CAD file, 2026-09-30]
experiments/plan-b-bench/stl/plan_b_lid.stl
59.0 x 59.0 x 7.00

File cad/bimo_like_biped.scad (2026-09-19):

// Parametric biped skeleton (a biped), servo-anchored massing model.
// Why: lock proportions + the 8x STS3215 joint layout before designing printable parts.
// Axes: X = forward, Y = left/right, Z = up. Servo bodies ARE the limb segments.

$fn = 40;

// --- STS3215 servo (measured: 45.2 x 24.6 x 35.1 mm) ---
sl = 45.2;   // long axis  -> runs along the limb
sw = 24.6;   // thin axis
sh = 35.1;   // tall/gearbox axis -> fore-aft depth
horn_d   = 13;
horn_off = 9.5;   // output disc offset from the top end

// --- structure ---
thigh = 26;  // bracket length hip-servo -> knee-servo
shin  = 26;  // bracket length knee-servo -> ankle-servo
foot_l = 84; foot_w = 48; foot_t = 6;

// --- torso + head (SBC cavity) ---
td = 46; tw = 104; th = 72;   // depth, width, height; width clears 2 hips side-by-side
hip_sep = 56;                 // leg center-to-center
hd = 46; hw = 62; hh = 42;    // head box

// --- pose (deg) — override at render time with -D to show range of motion ---
p_roll = 0; p_hip = 0; p_knee = 0; p_ankle = 0;
gait = 0;   // fore/aft hip split: +gait one leg forward, other back (walking demo)

col_servo  = [0.22,0.23,0.27];
col_struct = [0.80,0.82,0.85];
col_head   = [0.20,0.45,0.70];
col_horn   = [0.85,0.72,0.15];

// Servo with output axis along +Y and body long axis along Z (a vertical limb link).
module servo_pitch() {
  color(col_servo) cube([sh, sw, sl], center=true);
  color(col_horn)
    translate([0, sw/2, sl/2 - horn_off]) rotate([-90,0,0]) cylinder(d=horn_d, h=3);
}

// Simple structural bracket between two servos.
module link(len) {
  color(col_struct) translate([0,0,-len/2]) cube([sh*0.72, sw+5, len], center=true);
}

module foot() {
  color(col_struct) translate([foot_l*0.18, 0, -foot_t/2])
    cube([foot_l, foot_w, foot_t], center=true);
}

// One leg. side = +1 (left) / -1 (right). Forward-kinematic chain so joints bend.
module leg(side) {
  translate([0, side*hip_sep/2, -th/2]) {
    rotate([p_roll*side, 0, 0]) {                 // hip roll (about X)
      translate([0,0,-sh/2]) rotate([0,0,90]) servo_pitch();   // roll servo under torso
      translate([0,0,-sh])
        rotate([0, p_hip + side*gait, 0]) {       // hip pitch (about Y) + gait split
          translate([0,0,-sl/2]) servo_pitch();   // thigh = servo body
          translate([0,0,-sl]) {
            link(thigh);
            translate([0,0,-thigh])
              rotate([0, p_knee, 0]) {            // knee
                translate([0,0,-sl/2]) servo_pitch();  // shin = servo body
                translate([0,0,-sl]) {
                  link(shin);
                  translate([0,0,-shin])
                    rotate([0, p_ankle, 0]) {     // ankle
                      translate([0,0,-sh/2]) rotate([0,0,90]) servo_pitch();
                      translate([0,0,-sh]) foot();
                    }
                }
              }
          }
        }
    }
  }
}

module torso() {
  color(col_struct) cube([td, tw, th], center=true);
  // head with hollow SBC cavity
  translate([0,0, th/2 + hh/2])
    color(col_head) difference() {
      cube([hd, hw, hh], center=true);
      translate([0,0,-3]) cube([hd-8, hw-8, hh-6], center=true);
    }
}

module biped() {
  torso();
  leg(1);
  leg(-1);
}

biped();

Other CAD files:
cad/v6/step/foot_L.step
sim/meshes/v6/servo_elbow_R.stl
sim/meshes/v6/servo_shoulder_L.stl
cad/step/yaw_carrier.step
sim/meshes/v6/servo_pitch.stl
cad/step/bimo_v3yaw_articulated.FCStd
cad/step/foot.step
cad/step/gopro_base.step
cad/step/imu_carrier.step
cad/step/leg_link_print.step
cad/step/pelvis.step
cad/step/screws_battery_guard.step
cad/step/screws_board.step
cad/step/screws_deck.step
cad/step/screws_disc_y.step
cad/step/screws_foot.step
cad/step/screws_gopro.step
cad/step/screws_grip.step
cad/step/screws_head_stack.step
cad/step/screws_roll.step
cad/step/screws_tower.step
cad/step/screws_tray.step
cad/step/screws_yaw_carrier.step
cad/step/servo_ankle.step
cad/step/servo_pitch.step
cad/step/servo_roll.step
cad/step/servo_yaw.step
cad/step/tower.step
cad/step/yoke_pitch.step
cad/stl/foot.stl
cad/stl/gopro_base.stl
cad/stl/leg_link.stl
cad/stl/leg_link_print.stl
cad/stl/pelvis.stl
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

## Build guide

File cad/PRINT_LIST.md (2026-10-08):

# Print list

What to print for the robot, how to orient each part, what supports each one
needs, and how to slice and send it. The CAD is `cad/v6/`; its code map is
[README.md](README.md). What to buy is [docs/bom.md](../docs/bom.md), and how it
goes together is [docs/assembly.md](../docs/assembly.md).

**The code's default build is the robot to print**: arms on, the pelvis with
the girdle's deck pilots, 15 × STS3215 + 2 × STS3250 (the hip rolls) in the
mass line. The `ARMS=0` variant
(`neck_collar` for the neck, no girdle, no arm links, no pilots) exists for
the CAD checks and is **not a print target**: the collar's flange screws have
nothing to bite (their holes land in the Pi slide slot and the General Driver
lead slot, and there is no deck under the rest of the flange).

## Status

| can print now | wait |
|---|---|
| `foot_L`, `foot_R`, `ankle_link` ×2, `leg_link_v6` ×4, `hip_yoke_v6` ×2, `pelvis_v7`, `yaw_carrier_v6` ×2, `head_shell`, `head_face`, `neck_floor`, `shoulder_girdle_v6`, `arm_upper_v6_L/_R`, `arm_fore_v6_L/_R` | **`yaw_bearing_housing`**: its shoulder is sized to SKF's published ring dimensions; measure the generic bearings first ([docs/bom.md §5](../docs/bom.md)). |

**Fit check first (#79).** Before printing the full set, print one
`leg_link_v6` and one `hip_yoke_v6`. Fit them to a real servo, and check:

- the grip channel slides on;
- the disc screws engage;
- the supported horn-seating face sits flat on the disc.

## The parts

**How the masses are computed:** build123d volume × PETG 1.27 g/cm³ × 0.90
print factor (`parts_v6.mass_g`); the cut silicone soles are solid sheet,
estimated at 1.21 g/cm³ (no print factor) until weighed. They
are the rollup's, `docs/design-v6/parts_v6_rollup.txt`
(`cad/v6/parts_v6.py --no-export`).

**Bounding boxes** are in the model frame (mm). **Supports** are what to tell
the slicer; see [Supports](#supports-are-the-slicers-job).

| part | qty | g each | bbox | orientation on the bed | supports | notes |
|---|---|---|---|---|---|---|
| `pelvis_v7` | 1 | 173.8 | 99 × 124 × 72 | deck top down | **yes:** the two yaw-cell ceilings; the skin-window roofs near the housing floor | one print, the whole torso, with the girdle's ten deck pilots and the bearing housing's five pilot bosses; each yaw cell's ceiling has a hole for the servo's free-hub post and a relief for its back-cover platform |
| `yaw_bearing_housing` | 1 | 24.5 | 80 × 155 × 9.3 | the face that goes against the pelvis down | no | both hips' outer-race seats (Ø64.96 recess, −0.04 mm on the 6810-2RS, under a Ø62.6 shoulder), joined by a bridge, with a rear bar; five M2.5 × 8 flat-heads up into the pelvis |
| `yaw_carrier_v6` | 2 | 25.8 | 50 × 50 × 49 | horn-plate face down, bay walls rising | **yes:** the rear-wall connector window's ceiling, a 1 mm bar spanning 22.8 mm | carries the hip-roll servo in its bay, 5 mm below the horn plate; its round hub (Ø50.08, +0.08 mm) takes the bearing's inner race |
| `hip_yoke_v6` | 2 | 25.4 | 74 × 48 × 44 | on edge, model −Y on the bed, so the roll arms print as walls | **yes + 5 mm brim** | roll and pitch clevis in one print; see its notes below |
| `leg_link_v6` | 4 | 28.6 | 117 × 44 × 28 | on its back: web face on the bed | **yes**, build plate only: under the two round pad ends | thigh and shin are the same part |
| `ankle_link` | 2 | 13.6 | 65 × 43 × 38 | on its back (model +X up): the rear tine on the bed | **yes**: under the web (4.6 mm, from the plate) and under the front tine below the floor, standing on the rear tine's inner face, which seats the idler disc: clean it flat. The front wall bridges between the side walls | grips the ankle-pitch servo in a box around its base, forks onto the ankle-roll servo |
| `foot_L`, `foot_R` | 1 + 1 | 54.4 | 130 × 84 × 30 | sole down | no | a mirrored pair; each retention tab is braced by two fins on its outer face, sloped tops, support-free; a short near-row screw boss beside each disc |
| `head_shell` | 1 | 26.1 | 62 × 60 × 50 | base (horn plate) down; the dome is ≥ 45° | none expected | from `head.py` |
| `head_face` | 1 | 8.6 | 62 × 56 × 6 | flat, camera bosses up | no | |
| `neck_floor` | 1 | 4.0 | 46 × 45 × 5 | flat, bottom face down, pads and lugs up | no | the neck servo's seat (#90): screwed up into the neck tube's four bosses; the stator screws go up through it |
| `shoulder_girdle_v6` | 1 | 77.1 | 200 × 58 × 33 | base down | **yes**, build plate only | carries both shoulder servos and the neck tube (with the four bosses for `neck_floor`) |
| `arm_upper_v6_L`, `_R` | 1 + 1 | 27.8 | 169 × 38 × 29 | on its back, web face down | no | a mirror pair; open-front U with two end walls; grips the elbow servo |
| `arm_fore_v6_L`, `_R` | 1 + 1 | 41.5 | 182 × 44 × 27 | on its back, web face down | **yes**, build plate only: the two elbow-pad undersides start 5 mm off the bed | a mirror pair; the elbow fork, an end wall, 12 mm hand knuckle |

**Part notes:**

- **`pelvis_v7`**
  - The yaw-cell ceilings need support because the servo fills its cell to
    0.3 mm, so no support-free ceiling geometry exists.
  - Check the slice preview at the window roofs and at the deck-slot edges.
  - The deck does not seat the neck servo: its battery aperture runs under the
    whole servo. The seat is `neck_floor`.
- **Yaw carrier**
  - The carrier is not covered by the robot's printability audits.
  - The CAD models no break-away support under the connector window's ceiling
    bar, so the slicer has to support it.
- **`hip_yoke_v6`**
  - The pitch horn arm is a slab over the servo void, and the roll pad rims and
    arm plates start in mid-air.
  - The underside of the pitch horn arm is a support-interface face that clamps
    onto the horn disc. Check that it seats flat.
- **`leg_link_v6`:** the back web and both side walls sit on the bed. Only the
  lower-rear quarter of each round pad end overhangs, 5 mm up; support it from
  the plate. The knee pocket in the idler side wall prints with a 6.6 mm roof.
- **`head_shell`:** the printability audit flags a ceiling at the dome seam. It
  is believed to be a boolean artifact; confirm in the slice preview.
- **`neck_floor`:** a separate print because it hangs 5 mm below the girdle's
  print plane. Its counterbores and countersinks open onto the bed; the audit
  finds nothing to support.
- **`shoulder_girdle_v6`**
  - It is 200 mm long, so **centre it on the bed**.
  - Supports go under the trapezius-web window tops (34 mm spans), the
    grip-plate rib-relief roofs, and the bay disc-relief tops.

**Totals:** 22 prints, all PETG, from 16 STLs: ≈ 797 g before supports and
brims.

**Not printed:**

- `sole_tpu_L/R`: the soles are cut from 2 mm silicone rubber sheet
  ([docs/bom.md §7](../docs/bom.md)), not printed. Each is the foot plate's
  outline: 130 × 84 mm with 14 mm corner radii, the same for left and right.
  The STLs are that outline.
- `head.stl`: the shell and face fused, used for mass, the assembly checks and
  the sim plant.
- `neck_collar.stl` and anything built with `ARMS=0` (see the top of this
  page).

## Regenerating

```bash
.venv/bin/python cad/v6/parts_v6.py                    # every part -> cad/v6/stl + cad/v6/step, bed check, mass rollup
.venv/bin/python cad/v6/parts_v6.py --only foot_L foot_R
.venv/bin/python cad/v6/parts_v6.py --no-export        # the rollup alone
.venv/bin/python cad/v6/head.py                        # head_shell + head_face (+ the fused head), audits
```

- Each part module's `__main__` exports that part and runs its own audits.
  `leg_link_v6`, `hip_yoke_v6`, `shoulder_girdle_v6`, `neck_floor` and `arm_v6`
  rewrite their STL as they go.
- Run `sh cad/run_checks.sh` after any CAD change and before printing (see
  [README.md](README.md#the-gate)).

## Global print settings

**PETG for every part.**

- **Base settings:** 0.4 mm nozzle, 0.2 mm layers, 3 perimeters (every wall
  ≥ 2.4 mm is then perimeter-only), 30–40 % infill.
- **The profile that printed the prototype's PETG foot cleanly:** nozzle
  255 °C, bed 85 °C, 0.2 mm layers, 35 % infill.
- **Bed prep:** the FlashForge glue is a release layer on the PEI plate (PETG
  bonds hard to bare PEI). Degrease the plate with IPA.
- **Fits:** drop-in fits are `FIT = 0.30` mm (`cad/dimensions.py`). PETG runs
  hotter and strings more than PLA. On the first parts, check the snug
  interfaces: the grip channels on a servo case, the foot cradle, the pads on
  the discs. If anything binds, tune the flow or print a size test.
- **Filament:** keep PETG dry.
- **Bores:** small horizontal bores are teardropped toward each part's print-up
  direction, so their tops print without support. That is designed in;
  supports are not.

## Supports are the slicer's job

**Supports are never modelled into the STL.** Modelled fins put their anchor
tabs below the part, so the real first layer became disconnected stamps, and
the tabs fused into the part. The parts that need supports say so in the table
above, in their module's `SUPPORT_NOTE`, and in `check_printability.SUPPORTED`.

OrcaSlicer settings that work:

| setting | value |
|---|---|
| Enable support | on |
| **Support on build plate only** | **on**: otherwise every horizontal bore fills with support |
| Type | `normal(auto)`; `tree(auto)` also works and is gentler on round pads |
| Threshold angle | 30° |
| Top Z distance | **0.2 mm** (PETG welds to support at 0.1) |
| Support/object XY distance | 0.35 mm |
| Brim | outer only, **5 mm**, for tall narrow parts: `hip_yoke_v6` |

- Put the supported parts on their own plate so the setting does not leak onto
  the others.
- Read each supported part's audit findings (the `**` lines) against the slice
  preview.

**The printability audits** use `cad/check_printability.py`'s engine, run by
`cad/v6/audit_*.py` and by each module's `__main__`. They check each STL in its
print orientation for bridges, ceilings, ledges, islands, first-layer contact
and thin walls. The rules:

- PETG bridges 8 mm.
- A bridge is judged across its short side only when both ends are anchored. A
  window cut through a wall is a beam over its long span.
- The knife-edge threshold is 3.0 mm².

## Slicing

`cad/slice.py` slices a part, or a **plate** of parts printed together, into an
**OrcaSlicer project**, each part in its print orientation with the settings
above. Open the project in the GUI, check it, and print it from there.

```bash
python3 cad/slice.py leg_link_v6             # -> cad/gcode/leg_link_v6.3mf + .gcode (gitignored)
python3 cad/slice.py leg_link_v6 --copies 4  # four on the plate, this run only
python3 cad/slice.py feet                    # both feet, one plate -> cad/gcode/feet.3mf
python3 cad/slice.py --all                   # every plate, and every part on no plate
python3 cad/slice.py --harvest               # only read saved projects back
```

- **Open `cad/gcode/<part or plate>.3mf`** with File → Open Project.
  - The printer is the GUI's own printer preset, the one that holds the print
    host, so the plate prints from the GUI.
  - The process and filament are Flashforge's "0.20mm Standard" and "Generic
    PETG", marked as modified. The modified values are this file's spec.
  - The plate is already sliced: check the preview, then print it.
- **The settings live in `cad/v6/print_settings.json`.** They are layered:
  1. Flashforge's presets.
  2. The spec on top, from Global print settings and Supports above.
  3. One entry per part, with:
     - the orientation: `IDENT`, `RX180`, `RY_XUP`, `RY_XDOWN`, `RY_ROLL_WALL`,
       or a 3×3 matrix whose rows are the print axes in model coordinates;
     - supports, and copies;
     - overrides, in OrcaSlicer's own keys.
  4. Plates: parts printed together. **`feet`** is `foot_L` + `foot_R`. One
     process slices a plate, so its parts must agree on supports and overrides
     (`slice.py` refuses a plate whose parts don't). A plate's copies are its
     own: `--copies 2` puts two of each foot on it.
- **Changes made in the GUI carry forward.** Save the project (Cmd+S). The next
  `slice.py` run on that part or plate reads the saved project's changes back
  into `print_settings.json`:
  - any process or filament setting, including per-object settings (on a
    plate, for every part on it);
  - a part tipped onto another face (on a plate, that part only);
  - the number of copies.

  It prints what it changed, and keeps the saved project under
  `cad/gcode/.work/saved/`. Commit the JSON.
  - **Printer settings are not carried.** Change those in the GUI's printer
    preset.
  - **Painted supports or seams, modifier volumes and height-range modifiers
    cannot be carried.** `slice.py` then leaves that project alone and says so.
- **For each part it prints** the time, grams, height, supports, bed footprint
  and centre, and flags a part that lands off the bed. The footprint excludes the
  start gcode's purge line.
- **Where it runs.** On the Mac it drives `/Applications/OrcaSlicer.app`
  (`ORCA_APP` overrides the path). Elsewhere it runs the Flathub flatpak
  headless, as on mira. How it works and the upstream quirks it works around are
  in [docs/slicing.md](../docs/slicing.md).
- **One part departs from the table above** in `print_settings.json`:
  **`head_face`** is built in the assembly frame. Printed flat, outer face down
  and bosses up, its outer-face pocket becomes a ceiling of about 50 × 44 mm,
  1.8 mm above the bed. It is sliced with supports. Open: whether to keep the
  pocket and the supports.

### The printer

The printer is a **FlashForge Adventurer 5M Pro** at **`<printer-ip>`**, on
DHCP.

- **Fixed address:** if one is wanted, use a router DHCP reservation. Never set
  a static IP on the printer's panel: it ends up with two live addresses that
  flap.
- **LAN mode:** the working configuration has LAN mode off.
- **The bed is centre-origin, −110 … +110 mm in X and Y: centre every part on
  (0, 0).**
  - `slice.py` reports each part's measured centre.
  - A profile that emits corner-origin (0 … 220) coordinates puts the part in
    the +X/+Y corner, partly off the bed. If the centre is not (0, 0), shift
    X/Y by the part's own bounding-box centre before sending, and check the
    result stays inside ±110.
- **Upload over the LAN from OrcaSlicer.** Set these keys in the machine
  profile:
  - `host_type: flashforge`
  - `print_host: <printer-ip>` (bare IP; Orca adds port 8898 itself)
  - the printer's serial number, and its access code in `printhost_apikey`.
    Both are on the printer's panel under Settings → Network. **Keep them out
    of the repo.**
- **If an upload fails, check `host_type` before the network.** Without it,
  Orca falls back to plain HTTP on port 80, which this printer refuses.
- **Ports:**
  - 8898 is the printer's JSON API. `POST /detail` returns its status and its
    own `ipAddr`, which is the authoritative address.
  - 8899 is the raw `~M` command channel, not HTTP.
- **Sending from mira** is a separate host-side step, because the slicer's
  sandbox has no network.

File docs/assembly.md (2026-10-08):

# Assembly

How the robot goes together, written from the CAD in `cad/v6/`. **Nothing has
been built yet**: the first build (#79) will correct this guide.

**The figures** in each section are rendered from the CAD
(`cad/v6/render_steps_v6.py`, into `docs/assembly/v6_*.png`): installed parts
in their own colours, the part going in orange, backed off along its insertion
path, with a ghost at its seat. They show the left leg and arm; the right side
is built the same way.

**Other visual references:**

- **Fly-in filmstrips.** Every part flies in along its insertion path in
  `cad/v6/animate_v6.py`; the second row of each strip closes in on the parts
  that build is about:
  - [the robot](../cad/v6/renders/assembly_v6_flyin_arms_strip.png)
    (and the armless variant's [strip](../cad/v6/renders/assembly_v6_flyin_strip.png))

  The `.mp4`s are gitignored; regenerate them with the script.
- **STEP models to open in FreeCAD:** `cad/v6/step/assembly_v6_arms.step` (the
  robot) and the per-part STEPs ([cad/README.md](../cad/README.md)).

The fly-in is a feasibility check that builds the robot in place, bottom-up.
It is not the bench order; the figures and this text are. The differences:

- **Legs and hip stack:** the strip builds each leg up from the foot under the
  pelvis; on the bench the leg is a subassembly offered up onto the hip-roll
  servo (§8).
- **Hip-roll servo:** the strip brings it in from the front; on the bench it
  goes up into its bay from below (§7c).
- **Neck:** the strip lowers the girdle with its floor, then drops the neck
  servo in; on the bench the servo is screwed to the floor before the girdle
  goes on (§11a).

**Companion docs:**

- [Print list](../cad/PRINT_LIST.md) and [BOM](bom.md)
- [Wiring](wiring.md), [servo map and calibration](servo-map.md), and
  [bring-up](bringup.md)
- **Read [AGENTS.md](../AGENTS.md)'s bench-safety rules before any powered
  step.**

**Order at a glance:**

1. Prepare the servos (§2).
2. Build each leg from the foot up (§3–§6).
3. Build the hip stack into the pelvis (§7), then hang the legs on it (§8).
4. Fit the boards and power parts (§9).
5. Put the pack in (§10).
6. Build the neck into the girdle on the bench, then fit the girdle,
   shoulders, arms and head (§11).
7. Cable it (§12), power it up and calibrate (§13), then test the play (§14).

---

## 1. The joint: the servo is the axle

Every servo carries its joint on **both** ends of its output:

- a driven metal **horn** on one face;
- a **free-spinning idler disc** on the other face.

Both are Ø19.2 discs with 4 × M3 tapped on a Ø14 bolt circle. The case also has
mounting holes on both faces. They take **M2.5, not M3**. The rows sit 8.30 and
29.00 mm behind the axis on the horn face, and 8.30 and 32.75 mm on the idler
face, at ±10.25 mm across the width. So two printed parts meet at every servo:

1. **The distal link forks onto the output.** One plate bolts to the horn and
   the other to the idler disc: a two-sided joint with no separate bearing.
   This link turns with the horn.
2. **The proximal link grips the case.** It uses six M2.5 × 8 flat-head
   self-tappers: four on the horn-side face and two on the idler face.
   - **The heads must sit flush** in their 90° countersinks. On the prototype,
     proud heads on the grip plates rode the sweeping fork arms and skewed the
     links.

[`assembly/joint_anatomy.svg`](assembly/joint_anatomy.svg) shows this
arrangement. **Its screw callouts are not the current ones; use the tables
below.**

**Rules at every joint:**

- **Horn side first**, with the servo at mechanical zero and the limb in the CAD
  standing pose. Then do the idler side.
- **The idler boss is a locator, not a seat.** The printed Ø20 boss inside the
  case's Ø25 recess has about 3 mm of radial clearance. Concentricity comes from
  the four screws, so snug the idler screws at zero and check runout before the
  final torque.
- **Thread-lock the M3 disc screws** with a medium-strength thread-locker, kept
  off the plastic. Loose horn screws cost the prototype its zeros.
- **Watch the idler threads.** The idler disc's moulded M3 threads carry the
  far-side bending load, so inspect them after the first hours of walking. If
  they wear, the upgrade is a shoulder bolt through the disc or a thin washer
  bearing under the arm.

### Disc screws: length by stack, no washers

The discs are tapped through a thin flange:

- **2.5 mm on the horn and 2.1 mm on the idler**, measured on the bench and
  confirmed by sectioning `cad/vendor/ST3215.step` (`HORN_THREAD`,
  `DISC_THREAD` in `cad/dimensions.py`);
- an M3 × 6 has **5.6 mm** of thread (measured).

A disc screw has to engage **at least 1.5 mm and no deeper than the flange**. A
longer screw bottoms out and jacks the joint apart instead of clamping it, so a
washer is never the fix. The length therefore follows the stack under the head:

| stack under the head | where | screw | engagement |
|---|---|---|---|
| 3.0 mm: a 3 mm plate straight on the **horn** | leg-link fork horn pads; ankle-link front tine; hip-yoke pitch horn arm; yaw carrier; forearm at the elbow horn | **M3 × 5** | ≈ 1.6–2.0 of 2.5 |
| 3.0 mm: a 3 mm plate straight on the **idler** | ankle-link rear tine | **M3 × 5** | ≈ 1.6–2.0 of 2.1 |
| 3.6 mm: plate + 0.6 mm locating boss, **idler** | leg-link fork idler pads; hip-yoke pitch idler; forearm at the elbow idler | **M3 × 6** | 2.0 of 2.1 |
| 4.0 mm: plate on a 1 mm boss, or the head's 4 mm base, **horn** | hip-yoke roll horn arm; upper arm at the shoulder horn; head | **M3 × 6** | ≈ 1.6 of 2.5 |
| 5.8 mm: the pad sunk 1.35 mm behind the carrier's bay wall, **idler** | hip-yoke roll idler | **M3 × 8** | 1.8 of 2.1 |

**What this table rests on:**

- The stacks come from each part's CAD. The part modules' `SCREWS()` lists
  take their lengths from the stack (`dimensions_v6.disc_screw`), and
  `cad/v6/check_assembly_v6.py` checks every disc screw's engagement against
  its flange (the `discscrew` rows of
  [cad_rom_check.txt](design-v6/cad_rom_check.txt)).
- The M3 × 5's thread length (taken as 4.6 mm, the same 0.4 mm short of
  nominal as the measured M3 × 6) is not measured. **Confirm on the first
  joint of each kind before torquing the rest.**

### Fasteners by step

The numbers are totals for the robot (both legs, both arms), from each module's
`SCREWS()`.

| step | fastener | total |
|---|---|---|
| §3 foot tabs and near-row bosses | M2.5 × 8 flat-head self-tap | 12 |
| §4 grip channels (4 leg links, 2 ankle links) | M2.5 × 8 flat | 36 |
| §5 ankle roll (ankle-link tines) | M3 × 5 | 16 |
| §5 ankle pitch, knee (leg-link forks) | M3 × 5 horn / M3 × 6 idler | 16 / 16 |
| §6 hip pitch (hip-yoke pitch clevis) | M3 × 5 horn / M3 × 6 idler | 8 / 8 |
| §7a yaw-servo stators | M2.5 × 5 flat | 8 |
| §7b carrier to the yaw horn | M3 × 5 | 8 |
| §7c hip-roll servo into the carrier bay | M2.5 × 8 flat | 16 |
| §7e bearing housing up into the pelvis | M2.5 × 8 flat | 5 |
| §8 hip roll (hip-yoke roll clevis) | M3 × 6 horn / M3 × 8 idler | 8 / 8 |
| §9a–b Pi and General Driver | M2.5 × 10 pan (lower row) / M2.5 × 6 pan (upper row) | 4 / 4 |
| §9c power-pocket bosses | M2.5 × 8 pan | 2 |
| §11a neck floor to the tube / neck-servo stators | M2.5 × 8 flat | 4 / 4 |
| §11b girdle to deck | M2.5 × 8 flat | 10 |
| §11c shoulder servos | M2.5 × 8 flat | 8 |
| §11d shoulder horns | M3 × 6 | 8 |
| §11d elbow grips (upper arms) | M2.5 × 8 flat | 12 |
| §11d elbows (forearm forks) | M3 × 5 horn / M3 × 6 idler | 8 / 8 |
| §11e head to neck horn / head face / camera | M3 × 6 / M2.5 × 8 flat / M2 × 4 self-tap | 4 / 4 / 4 |

The robot has no heat-set inserts and no washers.

## 2. Servo prep (before any plastic)

1. **Incoming check** on every servo: weight, label and Model_Number
   ([bom.md §1](bom.md#1-servos)).
2. **IDs, one servo at a time.** Servos ship as ID 1, and two servos with the
   same ID do not enumerate. Assign each ID alone on the bus and label the
   case.
   - The ID map for the 17 joints is **not yet assigned** (#77).
     [servo-map.md](servo-map.md) holds the prototype's IDs 1–10 and the
     procedure (`tools/servo_tool.py`).
3. **Centre each servo at 2048, then fit its horn** with the centre screw.
   - The horn seats on discrete splines, so a mechanical zero is never exact.
     Calibration (§13) records the residual offset.
   - Centring first keeps each joint's travel clear of the encoder's 0/4095
     wrap. On the prototype, a zero at 3273 capped a hip's backward pitch at
     +72°.
   - **The two hip-yaw servos go in without their idler disc.** Nothing rides
     their idler side, which seats flat on the cell ceiling (§7a). Leave the
     disc off and keep it in the bag as a spare; the other 15 servos keep
     theirs.
4. **Gains.** On the four ankle-roll and knee STS3215s, write the
   position-loop P (register 21) and D (register 22) that the bench test (#73)
   settled. The hip rolls are STS3250s; their row in the table comes from the
   same bench. They are EEPROM registers: clear the lock flag (register 55)
   first.
   - **Do it with torque off. Every bus write is a motion command.**
   - Record the values per ID in servo-map.md.
   - A factory reset or a swapped spare comes back at P = 32.
5. **Orientation rules:**
   - **Legs are translations, not mirrors.** Leg links, ankle links, hip yokes
     and carriers are identical left and right, and every pitch-joint horn faces
     +Y (robot left) on both legs.
   - **Ankle-roll servos:** horn forward, cable end outboard.
   - **Hip-roll servos:** horn forward, cable end up.
   - **Yaw servos:** horn down. **Neck:** horn up.
   - **Feet and arms are mirror pairs.** The shoulder horns face outboard on
     both sides.

## 3. Feet ×2

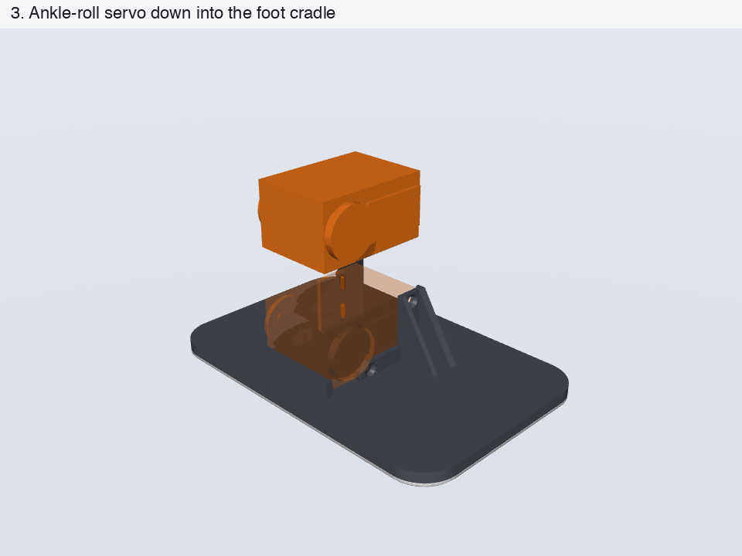
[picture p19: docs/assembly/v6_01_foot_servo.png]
Ankle-roll servo into the foot


1. **Bond the silicone sole** to the foot plate's flat underside: 2 mm
   silicone rubber sheet cut to the plate's outline (130 × 84 mm, R14 corners;
   `sole_tpu_L/R`). Degrease the PETG first. Silicone needs a silicone-rubber
   adhesive, or CA over a polyolefin primer, unless the sheet is self-adhesive
   ([bom.md §7](bom.md)).
2. **Drop the ankle-roll servo into the cradle** from above.
   - Its output axis runs fore-aft, with the horn forward.
   - Its output end sits against the inboard end stop, and the cable end points
     outboard. The lead leaves through the notch in the rear rail.
3. **Screw the two retention tabs:** the front tab onto the horn-side case face,
   the rear tab onto the idler face. Each takes **2 × M2.5 × 8 flat-heads** into
   the far hole rows, driven from outside between the tab's two bracing fins.
4. **Screw the two near-row bosses:** the short bosses beside the discs, one
   on each case face, take **1 × M2.5 × 8 flat-head** each into the low hole of
   the row nearest the output end. The idler-side boss stands just short of
   the connector trench, so plug the lead in before the servo goes into the
   cradle.

## 4. Grip channels: ankle link, shin, thigh

- **Which link grips which servo:**
  - `ankle_link` grips the **ankle-pitch** servo;
  - the shin (`leg_link_v6`) grips the **knee** servo;
  - the thigh (the same part) grips the **hip-pitch** servo.
- **Slide the link on from the case's cable end.** The case enters the grip
  channel lengthwise, from below. Sliding a link on "from the front" instead
  drives the horn disc into the grip plate.
- **6 × M2.5 × 8 flat-heads** per link: 4 on the horn-side face (rows 8.30 and
  29.00) and 2 on the idler face (row 32.75). All heads flush.

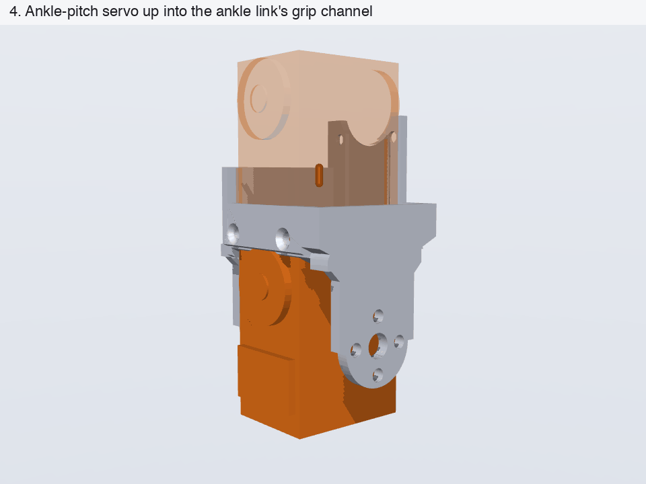
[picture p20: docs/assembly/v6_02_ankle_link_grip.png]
Ankle-pitch servo into the ankle link's grip channel


## 5. Close the leg joints: fork onto horn and idler

Each fork closes on the next servo's two discs. Work horn first at zero, then
the idler, with thread-locker, and check runout.

| joint | fork | horn side | idler side |
|---|---|---|---|
| ankle roll | the `ankle_link`'s two tines, lowered onto the roll servo in the foot: front tine to the horn, rear tine to the idler | 4 × M3 × 5 | 4 × M3 × 5 |
| ankle pitch | the shin's lower fork onto the ankle-pitch servo in the ankle link: horn +Y, idler −Y | 4 × M3 × 5 | 4 × M3 × 6 |
| knee | the thigh's lower fork onto the knee servo in the shin | 4 × M3 × 5 | 4 × M3 × 6 |

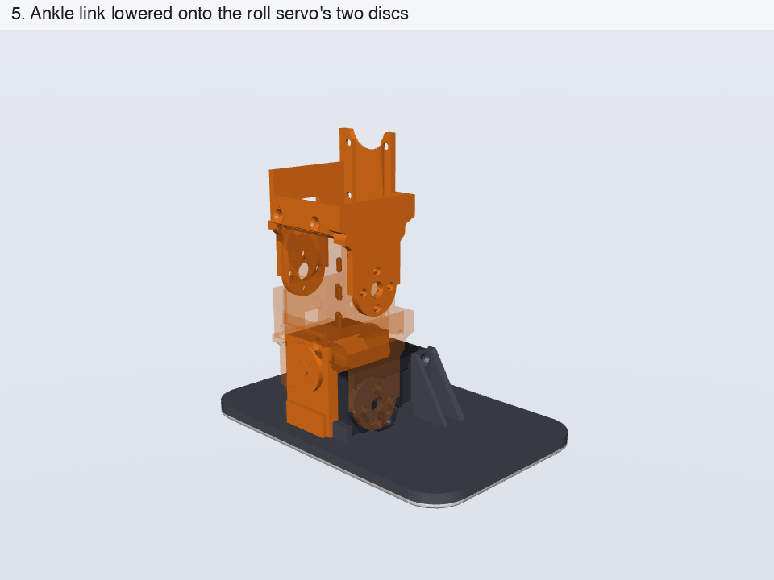
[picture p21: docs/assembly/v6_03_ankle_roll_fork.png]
Ankle link onto the roll servo

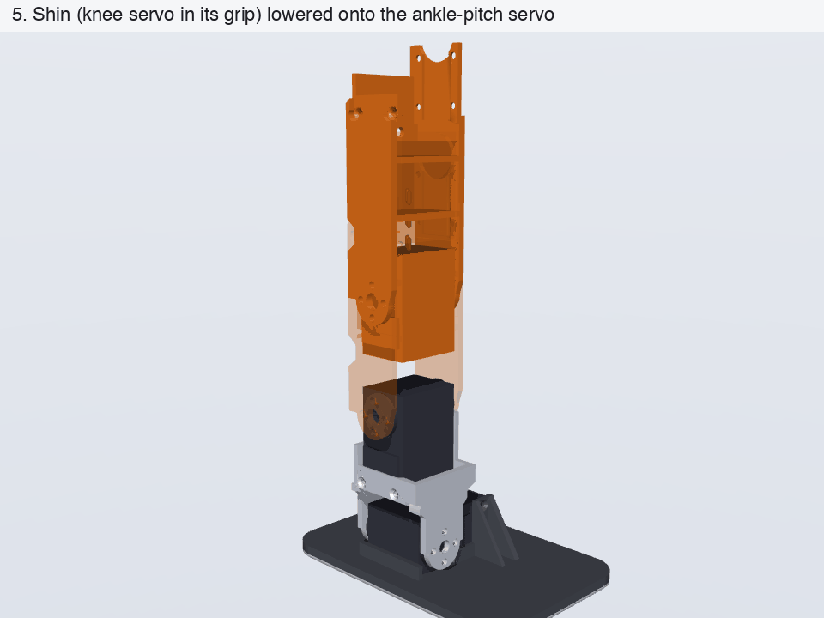
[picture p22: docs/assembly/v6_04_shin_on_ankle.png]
Shin onto the ankle-pitch servo

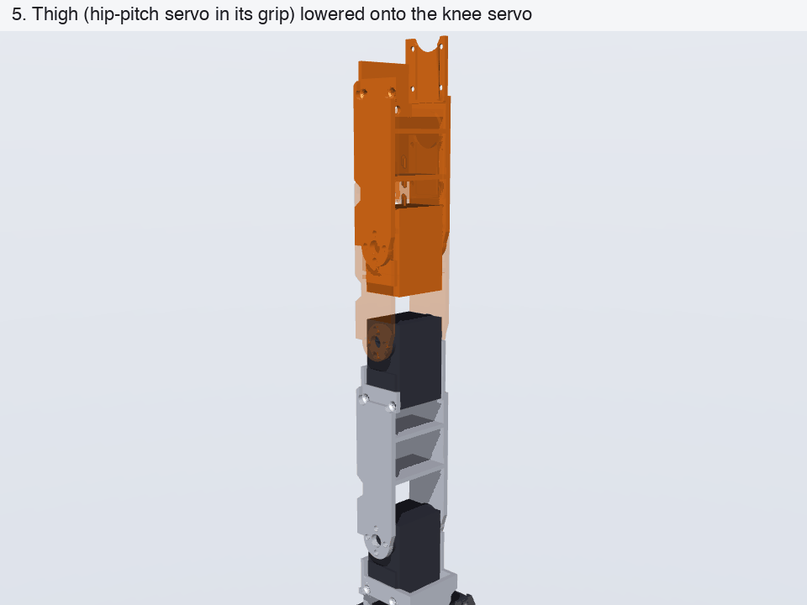
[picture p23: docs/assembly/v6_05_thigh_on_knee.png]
Thigh onto the knee servo


## 6. Hip yoke onto the hip-pitch servo

- **Pitch clevis.** Lower `hip_yoke_v6` onto the hip-pitch servo in the thigh.
  - Its pitch clevis (the lower half) straddles the servo's two discs: a horn arm
    on +Y (4 × M3 × 5) and an idler hub on −Y (4 × M3 × 6).
  - The yoke is one print, so there are no flange bolts.
- **Roll clevis.** The upper half waits for §8.

The leg is now a subassembly from the hip yoke down to the foot.

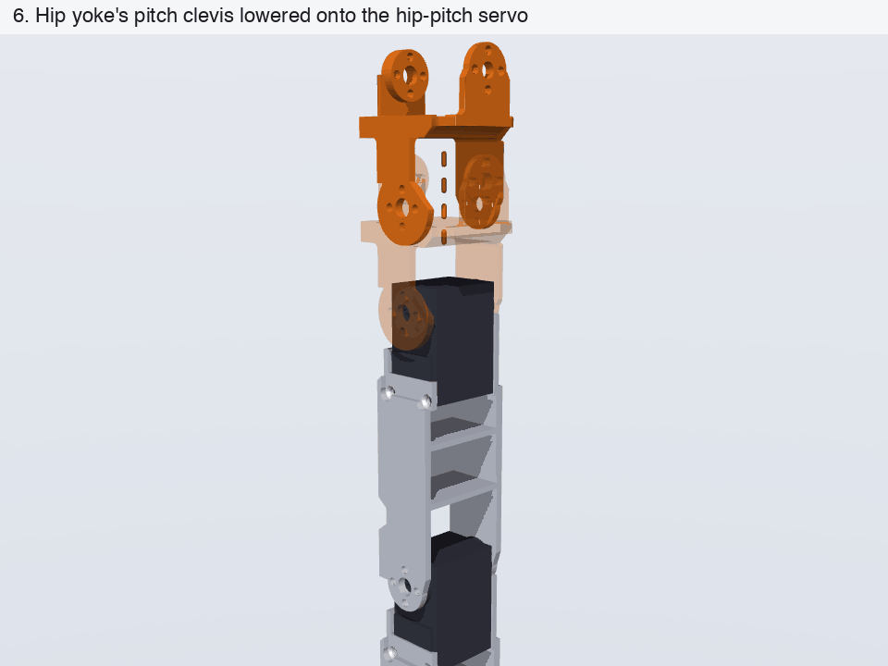
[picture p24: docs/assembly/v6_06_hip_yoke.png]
Hip yoke onto the hip-pitch servo


## 7. Hip stack in the pelvis (×2)

Work with the pelvis upright on a stand, so that the leg hangs below it later.
Everything in the battery layer is done **before the pack goes in** (§10).

### 7a. Yaw servo into its cell

1. **Offer the servo up into its cell from below** (the mouth has a 1.2 mm
   lead-in).
   - Output axis vertical, **horn down**, case length fore-aft, **no idler
     disc** (§2).
   - The idler-side case face goes up flat against the cell ceiling. Its four
     mounting holes are flush with the face, so the ceiling clamps them
     directly. The free-hub post (2.6 mm proud) passes into a hole in the
     ceiling, and the moulded back-cover platform (1.9 mm proud) into a
     relief: the face should sit flat with no rocking.
2. **Plug its leads first.** The bus ports sit in the connector trench on the
   idler face. A riser through the ceiling opens over the trench into the
   battery layer, so plug the leads in from above. From there they run through
   the battery layer to the deck's leg-bus slot.
3. **Drive 4 × M2.5 × 5 flat-heads down through the cell ceiling** into the
   idler-face rows (8.30 and 32.75). Reach them from above, through the deck's
   battery aperture, with the pack out. A 5 mm screw takes 2.4 mm of the hole,
   which the vendor STEP shows 3.0 deep; **check the hole depth on the first
   servo**, and use an × 6 only if it is at least 3.6 mm deep.

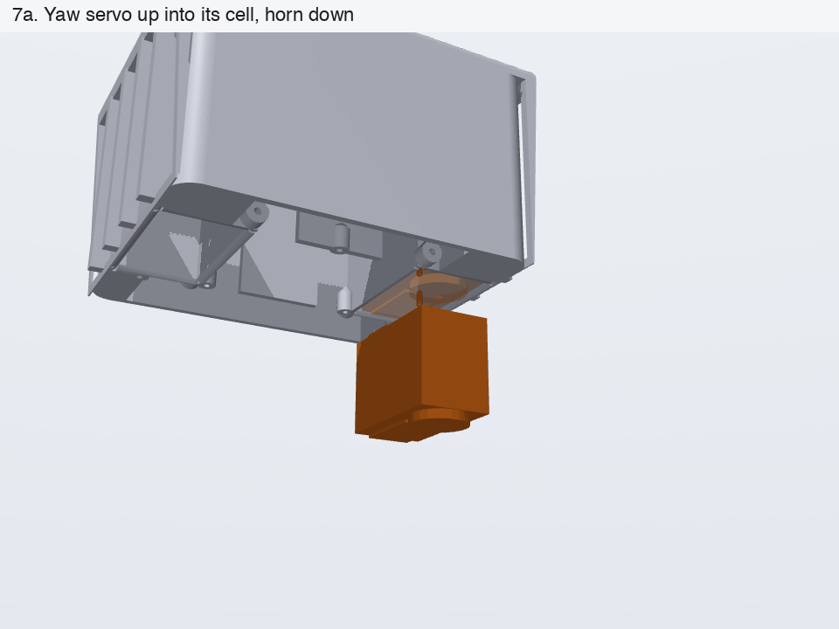
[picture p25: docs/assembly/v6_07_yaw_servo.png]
Yaw servo up into its cell


### 7b. Yaw carrier up onto the yaw horn

1. **Seat the carrier on the yaw horn** with the yaw servo at mechanical zero.
   Its horn plate mates the horn disc and its roll bay opens downward. **Square
   it before torquing**: a clocked carrier is a permanent yaw offset.
2. **Drive 4 × M3 × 5 up into the horn** through the bay ceiling, from inside
   the empty bay. Do this before the roll servo goes in.

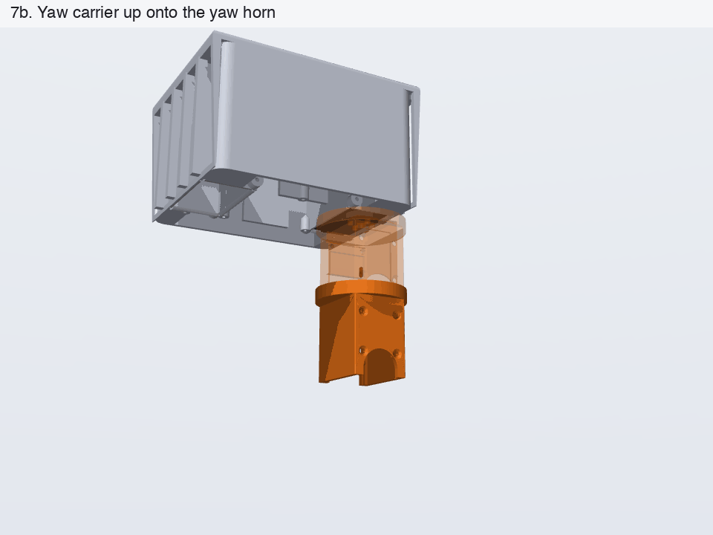
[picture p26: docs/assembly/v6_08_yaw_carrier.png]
Yaw carrier up onto the yaw horn


### 7c. Hip-roll servo up into the carrier bay

1. **Slide the servo up into the downward-open bay**, cable end first: output
   end down, horn forward.
   - The rear wall carries an idler seat with a detent channel for the case's
     moulded back-cover platform, so the servo should feel **snug against the
     rear wall** before any screw goes in. If it does not, check that the
     platform is running in the channel rather than sitting on top of it.
2. **Drive 8 × M2.5 × 8 flat-heads:** 4 through the front (horn) wall and 4
   through the rear (idler) wall, into the case. The carrier's 5 mm spacer
   keeps all eight below the bearing, so they can also be reached with the hip
   fully assembled (to change a roll servo, take the leg off and these eight
   out; the bearing and housing stay).

Do 7a–7c for **both hips** before the bearing housing: it carries both bearings.

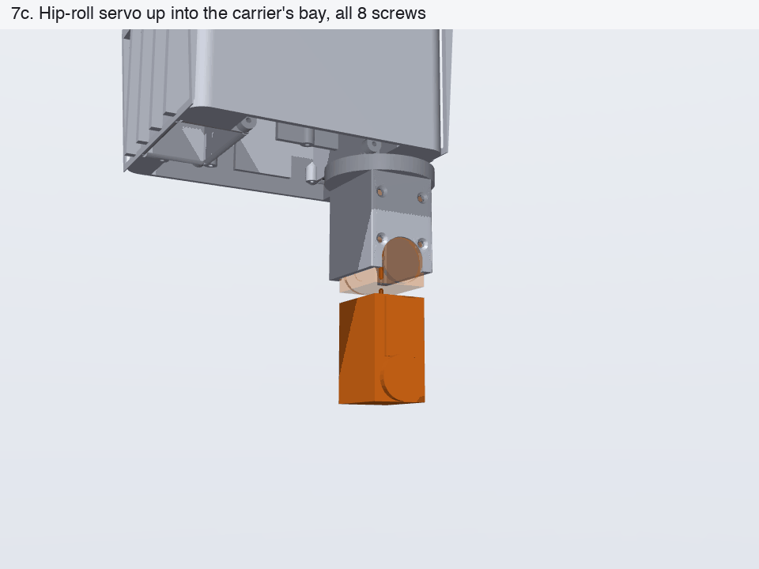
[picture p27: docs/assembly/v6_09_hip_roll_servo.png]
Hip-roll servo up into the carrier's bay


### 7d. The hip-yaw bearings into the housing (bench)

Each hip turns on a **6810-2RS** (50 × 65 × 7 mm, sealed; generic, so measure it
first: [bom.md §5](bom.md#5-hip-yaw-bearing)). Its outer race sits
in a recess of the **bearing housing** (`yaw_bearing_housing`, one print for
both hips, Ø64.96, −0.04 mm) against a shoulder, which takes the leg's thrust.
Its inner race goes on the carrier's round hub (Ø50.08, +0.08 mm). The housing
is a separate print screwed under the pelvis because the yaw servo goes up into
its cell, and the driver reaches the roll servo's upper screws, through the
space the housing occupies. Background:
[study-yaw-bearing.md](design-v6/study-yaw-bearing.md) (option A).

1. **Measure the bearings and the printed seats first.** Both fits are inside
   the printer's error band, so the housing and carriers print at nominal and
   are fitted with **retaining compound** (Loctite 641) on both seats.
2. **Press each bearing into its recess, pushing on the outer race only**,
   until it bottoms on the shoulder. The housing lies face down (the face that
   goes against the pelvis), recess mouth up.

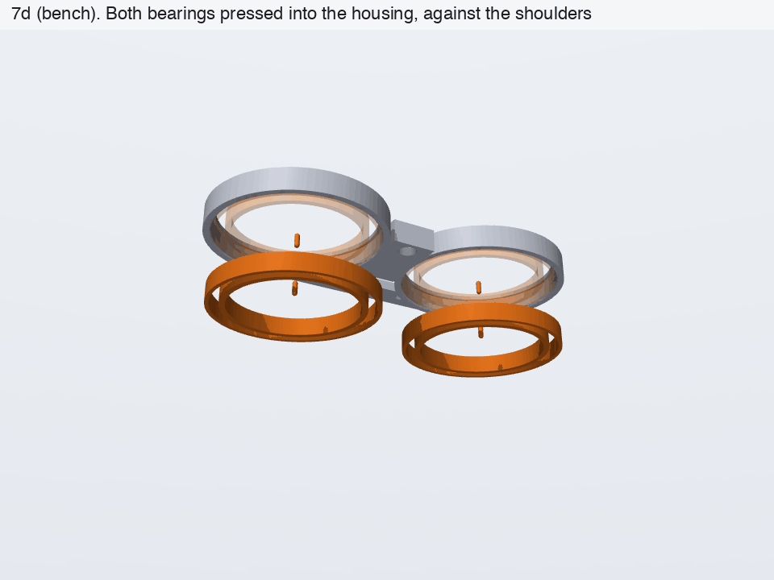
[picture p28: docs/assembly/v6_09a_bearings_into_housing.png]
Both bearings pressed into the housing


### 7e. Housing and bearings up onto both hubs

1. **Compound on both hubs**, then **offer the housing up from below**, square,
   over both carriers and roll servos: the bearings' bores clear everything
   below the hubs (the carriers' corners are trimmed to r 24.8 under the 25 mm
   bore).
2. **Push it home evenly** until its top face meets the cell block. The inner
   races slide onto the hubs as it goes. The fit is light; if a hub binds,
   ease the hub rather than force it, since that force goes through the balls.
3. **Drive 5 × M2.5 × 8 flat-heads up** into the pelvis's pilot bosses: four
   through the housing's rear bar and one through the bridge between the hips,
   on the centre line, into the cell block's front web.
4. **Turn each hip through ±45° by hand** before the compound sets: the carrier
   should turn on the bearing without touching the housing or the pelvis.
5. **Plug the hip-roll servo's leads** in the trench on its idler face,
   through the window in the bay's rear wall, and route them outside the
   housing.

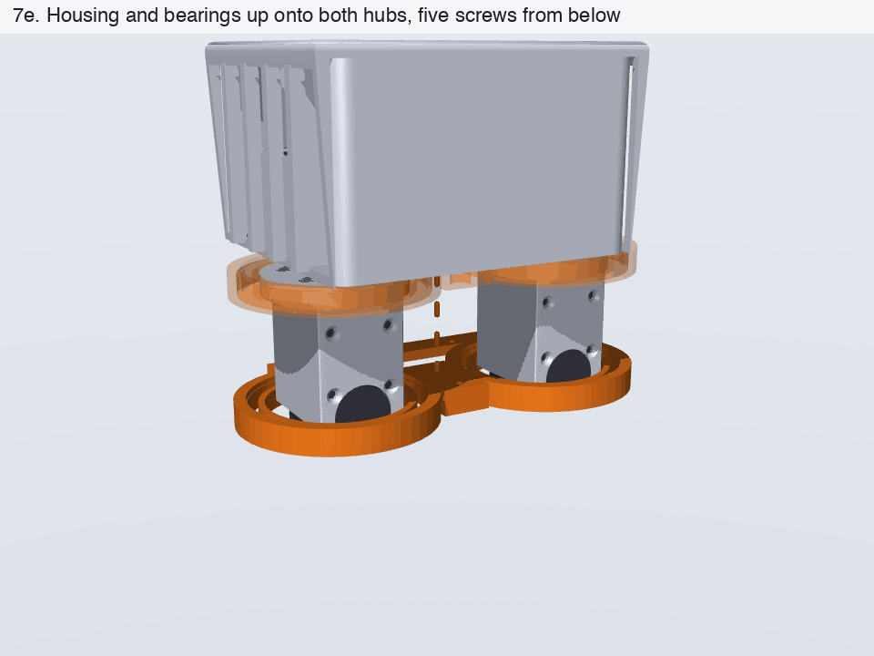
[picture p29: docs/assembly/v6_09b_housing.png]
Housing and bearings up onto both hubs


- **Never heat-set a bearing into PETG.** PETG must reach about 230 °C to flow,
  and a 2RS bearing's seals and grease are good to roughly 100 °C.
- **Until the generic bearings are measured, the ring dimensions in the CAD
  are SKF's** (61810-2RS1: inner ring
  shoulder d1 ≈ 54.67, outer ring shoulder D2 ≈ 61.8 mm). The housing's
  shoulder (Ø62.6) bears on the outer ring face, outside D2 and inside SKF's Da
  max of 63. Measure the bearings you have against those numbers before
  fitting; a different value goes into `cad/v6/dimensions_v6.py`.

## 8. Legs onto the roll servos

Offer each leg up so that the hip yoke's roll clevis straddles its roll servo:

- **Front:** the roll horn arm (on a 1 mm boss) bolts to the roll horn with
  **4 × M3 × 6**, at zero, with the leg hanging straight.
- **Rear:** the idler arm's long boss reaches through the slot in the carrier's
  rear wall to the idler disc, and takes **4 × M3 × 8**.
  - The heads land in a pad sunk 1.35 mm into the arm's outer face. That sink
    is what brings the screws into thread, so do not fill or file it.
  - Snug at zero, then check runout.

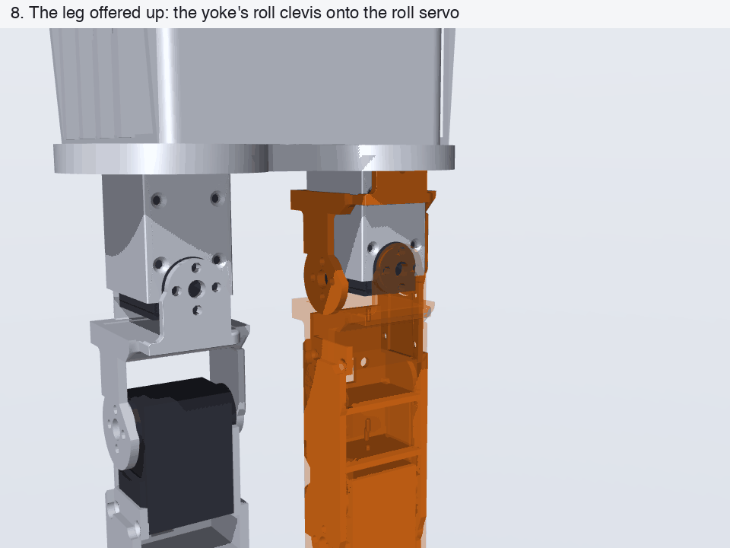
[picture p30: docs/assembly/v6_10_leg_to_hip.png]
The leg offered up onto the roll servo


## 9. Torso electronics

The Pi and the General Driver stand vertically in their own columns, fore and
aft of the yaw cells. Each slides straight down its guide channel through its
own slot in the deck.

- **Screws, each board:** the lower row takes **M2.5 × 10 pan** screws into
  standoff bosses; the upper row takes **M2.5 × 6 pan** screws into wall pilots.
  A boss in the upper row would block the slide.
- **Driver:** a few of these screws sit close to walls and need a slim driver.

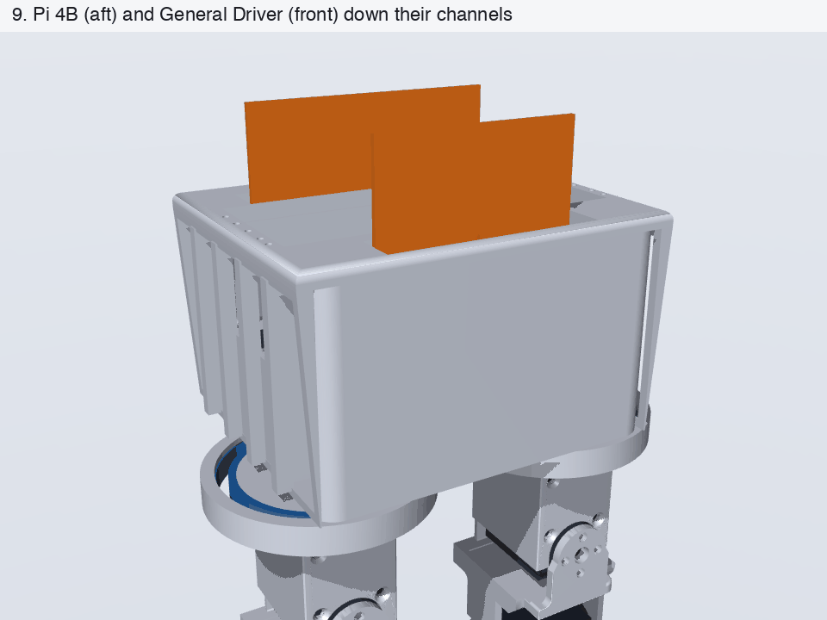
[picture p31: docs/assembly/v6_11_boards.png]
The two boards down their channels


### 9a. Raspberry Pi 4B (aft wall)

- Fit the low-profile heatsink first. The column has 16 mm of depth behind the
  board.
- The USB/Ethernet stack faces +Y, through the side window. The USB-C, HDMI and
  camera edge faces up under the deck.
- Connect the camera cable at the top edge and route it toward the neck.

### 9b. General Driver (front wall), and its IMU

- The board's bus edge faces up under its deck slot, so the servo leads drop
  straight onto its two bus ports, H5 and H6. Both ports carry the same nets.
- **The IMU is the board's onboard QMI8658C.** The board's mounting fixes the
  IMU's axes. The firmware applies a mounting rotation (`imu::Mount`), which has
  to be set for this orientation as part of the 17-joint port (#81).

### 9c. Power pocket

- **Protection board and 5 V buck.** Both stand on edge in the pocket just
  forward of the pack (one 60 × 25 mm face, 8.4 mm deep), reachable through the
  deck aperture. There are two M2.5 bosses; **how the boards are fixed is open**
  (the buck's holes take M2).
- **Power path:** pack lead → protection board → fuse → switch → XH pigtail to
  the board's inlet. Check polarity against the silkscreen "− +".
- **Bulk capacitor:** solder it across the servo bus at the board, observing
  polarity.
- **Buck output:** it feeds the Pi's USB-C.
- The current budget and the inlet are open (#77; [bom.md §3](bom.md#3-power)).

## 10. The pack (before the girdle)

1. **Finish everything in the battery layer first:** the yaw stators (§7a),
   the yaw leads, the power pocket (§9c).
2. **Stick two 1 mm adhesive foam pads on the cell ceilings**, one per cell,
   clear of the post holes. The yaw servos' free-hub posts come up flush with
   the ceiling and turn with the hip; the pads hold the pack 1 mm off them.
3. **Lower the pack through the deck aperture.** It lies transverse on the
   pads.
4. **Belt it** with the 15 mm hook-and-loop strap through the belt slots.

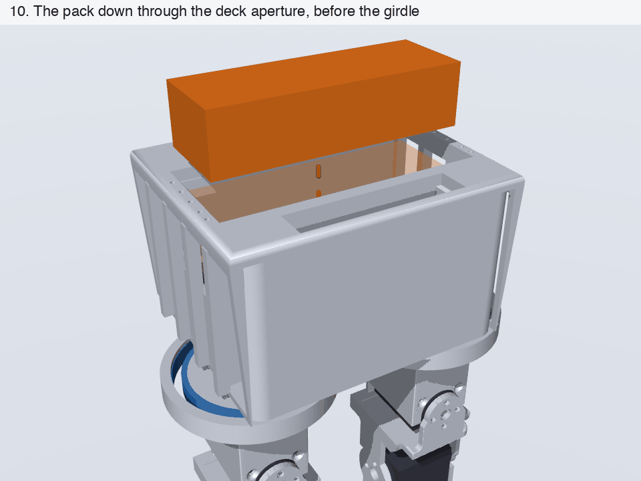
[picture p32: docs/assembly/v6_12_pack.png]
The pack down through the deck aperture


The girdle's neck tube, the neck floor under it and the aft tie span the
aperture, so **the pack cannot come out while the girdle is on**. Swapping it
means lifting the girdle, which is held by ten deck screws; the neck stays in
the girdle.

## 11. Girdle, neck, shoulders, arms, head

The bench order, girdle first. The neck floor sits 4.0 mm over the pack, so
the neck is built into the girdle before the girdle goes onto the robot.

### 11a. Neck into the girdle (on the bench)

1. **Neck floor into the tube.** Offer `neck_floor` up into the bottom of the
   girdle's neck tube, pads up, and drive **4 × M2.5 × 8 flat-heads** up
   through its lugs into the four bosses on the tube's side walls.

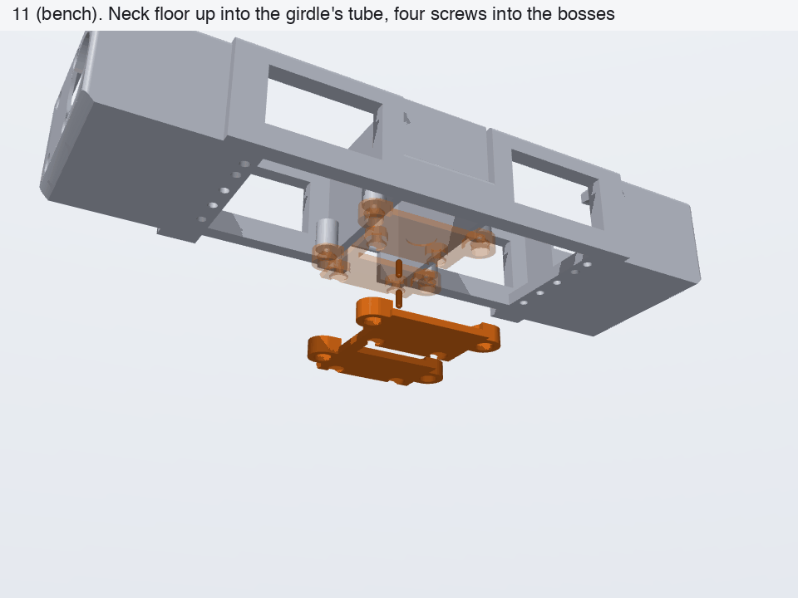
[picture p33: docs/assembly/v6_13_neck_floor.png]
Neck floor up into the girdle's tube
   

2. **Plug the neck servo's leads first.** The bus ports face down, in the
   connector trench on the idler face. The floor has a window under the trench,
   open toward the robot's left (+Y), so the plugs pass it and the leads leave
   sideways at floor level.
3. **Drop the neck servo into the tube from above**, horn up, case length
   fore-aft with the cable end aft. Its idler face lands on the floor's four
   pads; the turning idler disc and hub clear the floor by 0.6 mm.
4. **Drive 4 × M2.5 × 8 flat-heads up through the floor and the pads** into
   the idler-face rows (8.30 and 32.75). The heads seat in 1 mm counterbores,
   so each screw bites 4 mm into the case.

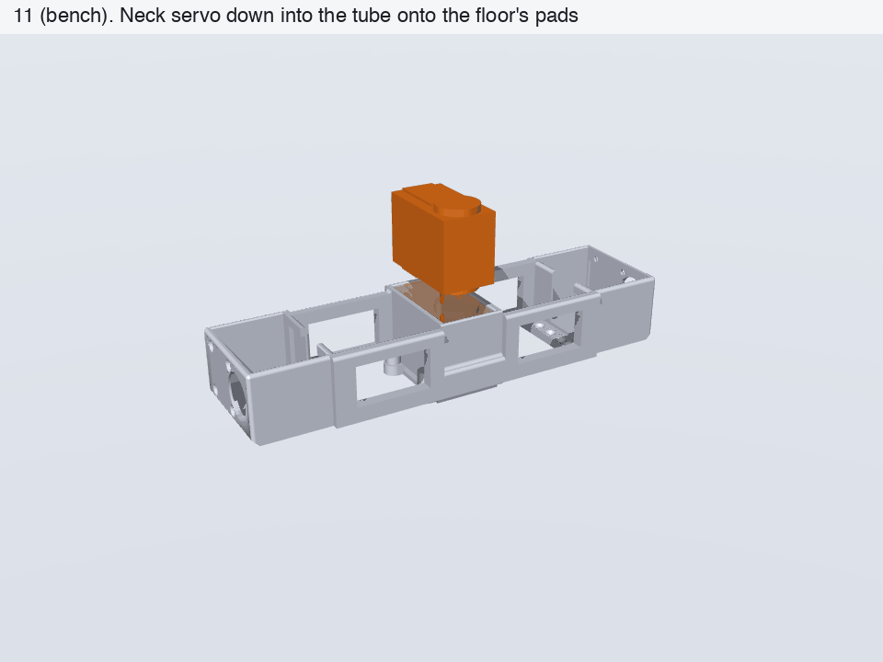
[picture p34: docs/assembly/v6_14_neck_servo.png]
Neck servo down into the tube
   

### 11b. Girdle onto the deck

- **Lower the girdle onto the deck**, the neck floor passing down into the
  battery aperture over the pack. Lead the neck's bus leads up beside the tube.
- **Screw it down with 10 × M2.5 × 8 flat-heads** from above into the deck
  pilots on the two edge rails (x −27, −18, −9, 0, +6 mm at y ±57 mm). The
  rail pilots are clear of the pods, so the shoulder servos can go in before
  or after.

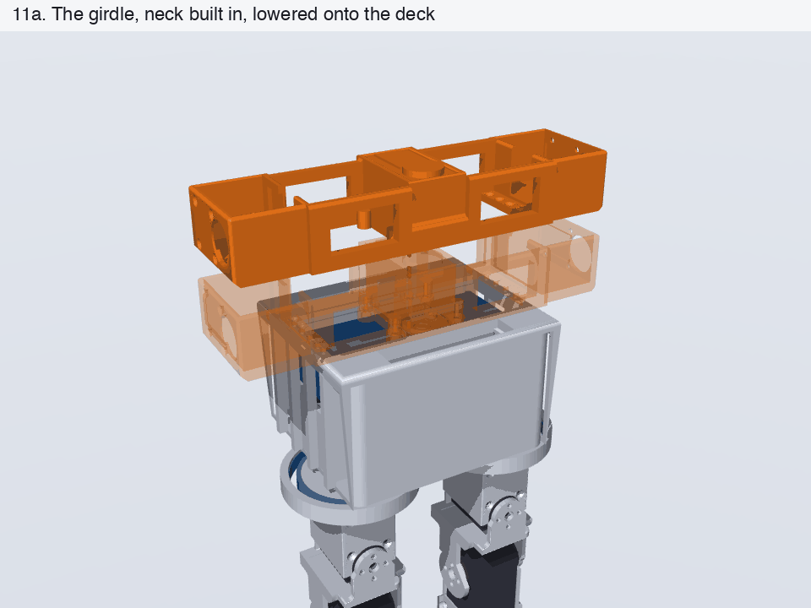
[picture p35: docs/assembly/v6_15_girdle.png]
The girdle lowered onto the deck


### 11c. Shoulder servos

- **Drop each servo straight into its open pod** from above: case length
  fore-aft, width vertical, horn outboard.
- **Screw it with 4 × M2.5 × 8 flat-heads into the horn-side case face, from
  outboard.** The inboard face sits 1.24 mm off the housing skin, where no
  driver fits.

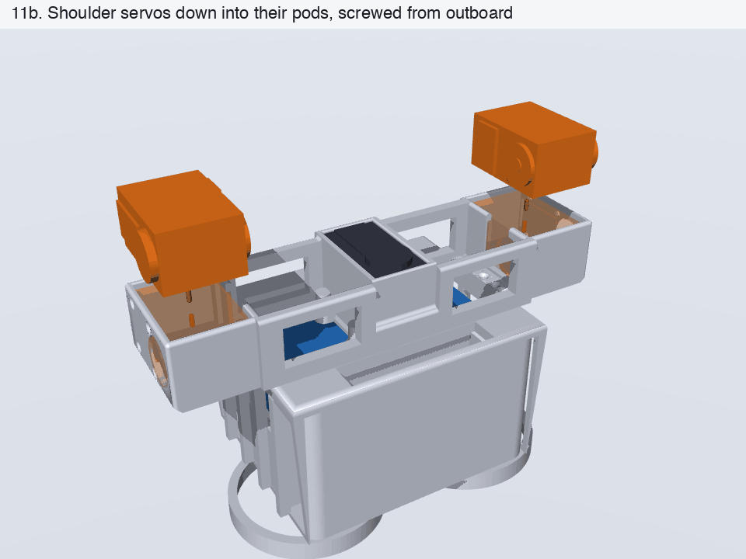
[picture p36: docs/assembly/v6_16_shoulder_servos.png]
Shoulder servos into their pods


### 11d. Arms (a mirror pair)

1. **Upper arm onto the shoulder horn.** Offer it straight in along the joint
   axis, with the shoulder at zero (arm hanging). It is a single-sided horn
   joint.
   - **4 × M3 × 6** (the horn plate sits on a 1 mm seating boss: a 4.0 mm
     stack), driven through the access bore in the arm's outboard face.

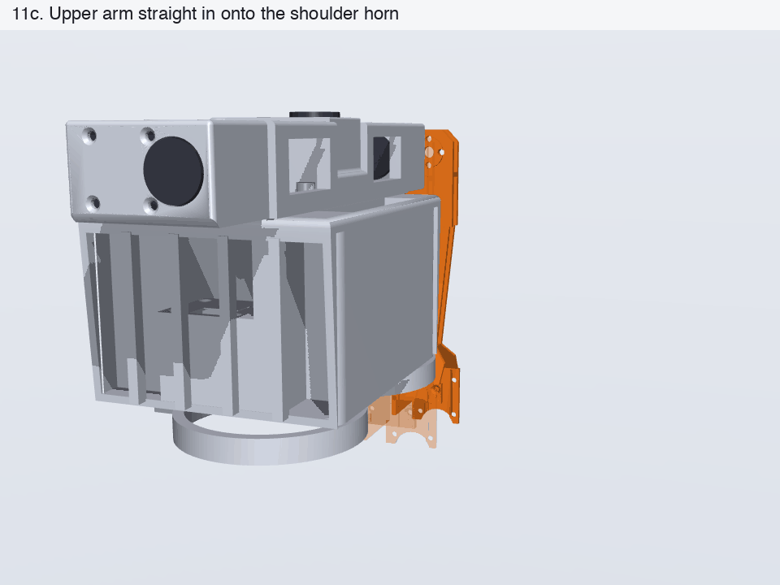
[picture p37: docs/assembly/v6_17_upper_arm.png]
Upper arm onto the shoulder horn
   

2. **Elbow servo into the upper arm.** Slide it into the grip channel at the
   upper arm's lower end from the front, output end down, horn outboard, so the
   case runs up the arm. **6 × M2.5 × 8 flat-heads**: four from outboard, two
   from inboard. Plug the shoulder-to-elbow lead in first and take it out
   through the web window just above the case.

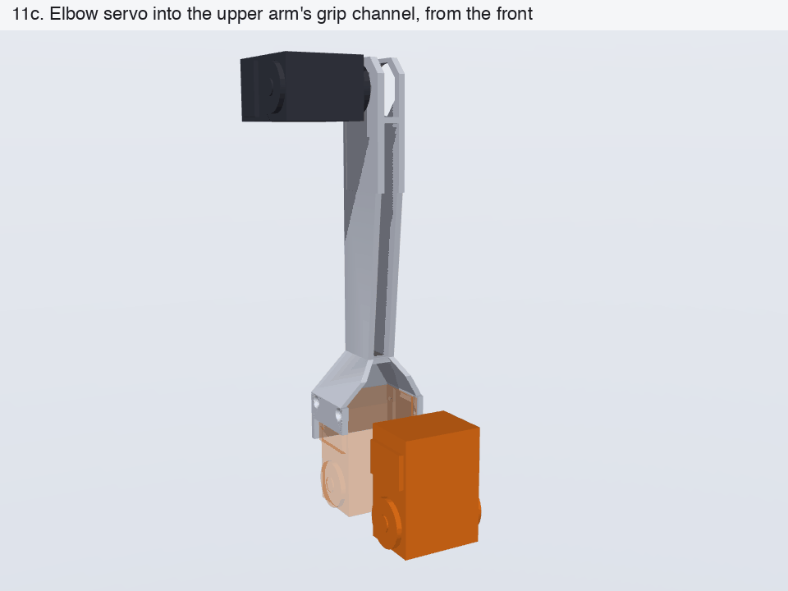
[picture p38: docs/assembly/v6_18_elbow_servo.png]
Elbow servo into the upper arm
   

3. **Forearm onto the elbow servo.** Lift it up so its fork tines pass either
   side of the servo's output end onto the two discs, with the elbow straight:
   - horn side **4 × M3 × 5**;
   - idler side **4 × M3 × 6**.

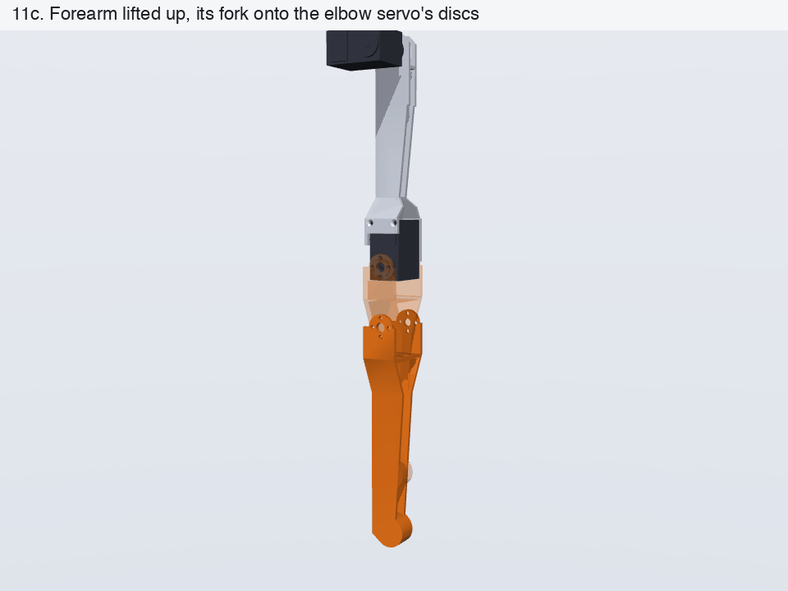
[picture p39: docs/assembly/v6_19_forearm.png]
Forearm onto the elbow servo
   

### 11e. Head and camera

1. **Camera onto the face.** Fit the Camera Module 3 to the four M2 bosses on
   the inside of `head_face` (4 × M2 × 4 self-taps), lens through the aperture.
2. **Route the camera cable** through the slot in the head's base beside the
   neck axis. Leave a slack loop for ±90° of yaw.
3. **Shell onto the neck horn.** Seat `head_shell` on the neck horn with the
   neck at zero and the head facing forward. Drive **4 × M3 × 6** through the
   4 mm base plate, from inside the open shell.
4. **Close the face** with **4 × M2.5 × 8 flat-heads**.

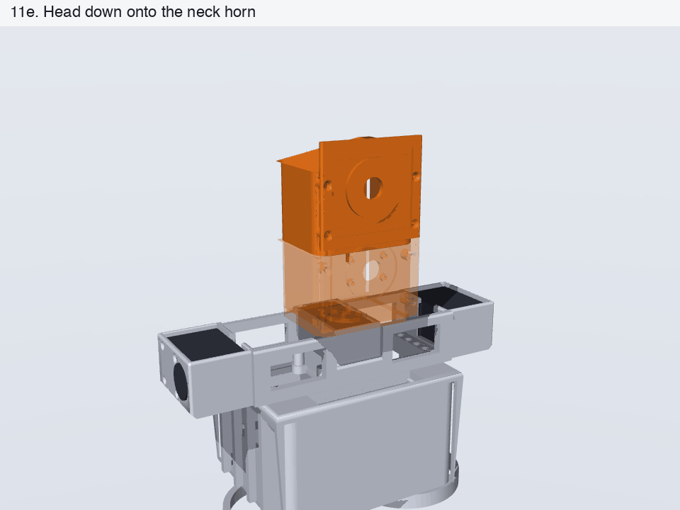
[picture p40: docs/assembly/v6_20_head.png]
Head onto the neck horn


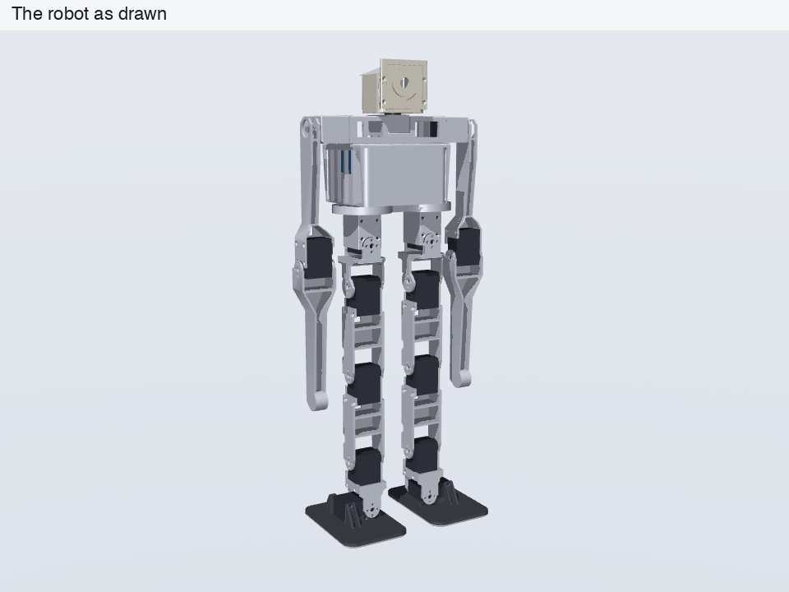
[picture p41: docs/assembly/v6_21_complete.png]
The robot as drawn


## 12. Cabling

**The harness is not drawn yet** (#77): no 17-joint ID map, no per-hop lead
lengths, and no current budget.

**What the CAD provides for it:**

- **Yaw servos:** a lead riser through each cell ceiling into the battery layer.
- **Deck:** two 12 × 6 mm leg-bus slots at y = ±42 mm.
- **Roll servos:** their ports face rearward through the carrier's rear-wall
  window.
- **Boards:** the General Driver's bus edge faces up under its deck slot, and
  the Pi's camera edge faces up under the deck.
- **Neck:** the leads leave the plugs through the neck floor's window, toward
  +Y, and rise through the deck aperture beside the tube; the tube also has a
  window at the servo's cable end.

**Rules:**

- **Daisy-chain.** Each servo has two paralleled ports, so the bus hops from case
  to case. Each servo ships with a 150 mm lead; where a hop needs more, use an
  extension lead.
- **Leave a slack loop across every joint, sized at full flexion.**
  - That means knee 130°, hip pitch −120°, and the shoulder through its whole
    −90° … +200°: its lead crosses a joint that folds 290°.
  - Fold each joint to its limit before cinching the zip ties.
- **Strain relief for the arm leads is not designed yet.**

## 13. First power-up and zero calibration

**Before anything powered,** read AGENTS.md's bench-safety rules:

- any bus write is a motion command;
- opening the serial port reboots the board and eats the first command;
- check torque before a bench run;
- disarming does not lower the robot.

Bare board to first arm: [bringup.md](bringup.md).

**The firmware currently drives the prototype's 10 joints.** The 17-joint port
(IDs, calibration blob, observation spec, and the register-21 check at boot) is
open (#81). The procedure is the one the prototype uses:

1. **Zero.** Standing is angle zero for every joint.
   - Hold the robot in the CAD standing pose on a stand, then run `cal zero` and
     `cal save`. The zeros are stored in NVS.
   - The table lives in [servo-map.md](servo-map.md); update it and
     `firmware/main/asbuilt_cal.h` in the same commit.
   - **Re-zero after any mechanical work on a joint.** Tightening loose horn
     screws moved the prototype's zeros by up to 4.7°.
2. **Directions.** Verify every joint's sign against the simulation at low
   torque limit and slow speed before trusting any gait. A wrong knee sign
   drives the knee into hyperextension.
3. **Gains.** Read registers 21 and 22 back on every servo the table raises.
4. **Pack.** Land the robot by 3.5 V/cell (10.5 V).

## 14. Play test, per roll joint

Measure play on every roll joint (both hip rolls, both ankle rolls) on the
assembled robot, **before the first walk**. Do the knees and hip yaws too.

- **The requirement:** ≤ 3° per roll joint, with ≤ 1° as the target. At ≤ 1°, a
  3× gain is enough (DESIGN.md §4).
- **The method is tilt hysteresis.** The encoders sit on the shaft side of any
  slop, so they cannot see it; the IMU can.
  - With the robot standing, step one joint slowly out and back: 0.5° steps to
    ±4°, slow slew, 1 s settle.
  - Read the torso tilt from the IMU at each step. The dead band at reversal is
    the play.
- **Tools.** `tools/joint_sweep.py` runs this on the prototype; its ID and zero
  table is the prototype's. For hip yaw, `tools/yaw_probe.py` yaws both hips
  together and reads the pelvis's yaw from the gyro.
- **On the prototype** this test found 2–3° at a hip roll.
- **If a joint is over the limit,** check the disc screws, the idler seating and
  the grip screws, then re-zero.

## Open

| item | where |
|---|---|
| ID map, harness, lead lengths, current budget, fixing of the power boards | #77 |
| 17-joint firmware: calibration, IMU mounting rotation, register-21 check | #81 |

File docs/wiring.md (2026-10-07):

# Wiring and power

The robot runs on one 3S pack and one controller board, the Waveshare **General
Driver for Robots** (ESP32). The board carries all 17 servos on one serial bus. A
Raspberry Pi 4B has its own 5 V buck. There is no custom electronics.

Related documents:

- board connectors and sensor headers: [sensor-expansion.md §1](sensor-expansion.md#1-the-boards-connectors)
- servo IDs, registers and calibration: [servo-map.md](servo-map.md)
- the procedure from a bare board to the first arm: [bringup.md](bringup.md)
- bench safety: [AGENTS.md](../AGENTS.md#bench-safety)

The firmware currently drives the 10-joint prototype (servo IDs 1–10). What this
page says about 17 servos is the robot's design. Anything marked **open** is not
settled yet.

## The board

| | |
|---|---|
| board | Waveshare General Driver for Robots, rev 1.2. ESP32-WROOM-32UE module (ESP32-D0WD-V3), 4 MB flash |
| outline | **65.01 × 56.01 mm**, holes on a 58 × 49 mm grid, per the dimension drawing. The wiki says "65 × 65 mm"; that is wrong |
| power in | H1, a JST XH 2-pin connector (item 10 on the vendor's connector diagram), silkscreened "− +" |
| input range | The wiki says "DC 7-13V". The rev 1.2 silkscreen says "DC 9-12.6V". This is unresolved. A 3S pack, used between 9.9 and 12.6 V, is inside both |
| servo bus | H5 and H6 (item 13). UART1 at 1 Mbaud, GPIO 18 RX / 19 TX |
| console | the USB-C port silkscreened `USB`: a CP2102N to UART0 at 115200, with DTR/RTS auto-program |
| IMU | the on-board QMI8658C, 0x6B on I²C (GPIO 32/33) |

- GPIO constants are in `firmware/main/board.h`.
- The schematic and dimension drawing are in [datasheets/general-driver/](datasheets/general-driver/).

## Power path

```
3S LiPo, 11.1 V nominal, 12.6 V full
  │
3S protection board ─────────── ≥ 15 A continuous, over-discharge cut-off ~3.0 V/cell
  │
inline fuse ─────────────────── ATM mini-blade, 15 A (10 A once the peak is measured)
  │
switch ──────────────────────── the E-stop that does not need the radio
  ├── Pololu D24V50F5, 5 V / 5 A ── USB-C ── Raspberry Pi 4B        (tap point: open)
  ├── bulk capacitor, 1000 µF ≥ 25 V low-ESR, across V+/GND
  │
H1  JST XH 2-pin inlet ──────── 3 A per contact; everything below is on the board
  │
AO4407 P-FET (reverse polarity) ── SW1 slide switch
  │
DC_IN ─┬── H5, H6 servo ports: all of the servo current
       │
       └── R11 0.01 Ω (INA219) ── VIN ── MP8759 5 V buck ── 5 V rail ── AMS1117 ── 3V3
                                          (ESP32, on-board sensors, 40-pin header 5 V)
```

The board side of this diagram is read off the vendor schematic. The parts above
H1 are the robot's harness.

### Pack

The pack is a 3S LiPo, bought to a spec filter:

- 11.1 V nominal. Not 11.4 V "HV": a HV pack charges to 13.05 V, which is above the board's 12.6 V silkscreen.
- 2200–2600 mAh.
- ≤ 105 × 36 × 26 mm. That is the pelvis battery layer, `BATT` in `cad/v6/dimensions_v6.py`.
- 150–190 g.
- XT30 or XT60 connector, 25C or better.

An RC LiPo has no protection circuit inside it. If a pack will sit for more than a
few days, storage-charge it to 3.8 V/cell.

### Protection board

- 3S, ≥ 15 A continuous on the pack lead, over-discharge cut-off about 3.0 V/cell, on the balance leads.
- It is the backstop that does not depend on the firmware, below battguard's 3.3 V/cell landing line ([Battery protection](#battery-protection)).
- A UART "smart" BMS (JBD/Daly 3S class) in its place would report per-cell voltages. Whether that is wanted is **open**.
- The protection board and the buck share a 60 × 8.4 × 25 mm pocket beside the pack (`PWR_BOARD`).
- The pelvis bosses in that pocket are placeholders until both boards are in hand (`cad/v6/pelvis_v7.py`).

### Fuse

- The fuse is a mini-blade (ATM) fuse in an inline holder on the pack lead.
- It protects against a dead short. The board's own servo path has a reverse-polarity FET and a switch, but no fuse.
- Start at 15 A. Drop to 10 A only after the real peak has been measured.
- **Never use a polyfuse/PPTC.** It takes seconds to trip, and its series resistance sags the rail the rest of the time.

### Switch

- An inline switch on the pack lead. It is the robot's real E-stop ([control-channel.md](control-channel.md)).
- The board's own SW1 switches `DC_IN` behind the inlet. The schematic gives no rating for it. The Waveshare FAQ says the bus-servo current "is controlled by a switch" ([Current](#current-the-open-constraint)).

### Inlet

- H1 is a JST XH 2-pin connector, 2.50 mm pitch.
- JST rates each contact at 3 A AC/DC at AWG #22, and the contacts take AWG #30–#22 (`JST-XH-connector-datasheet.pdf`).
- A 20 AWG pack lead does not go into the housing. Splice it to a 22 AWG XH pigtail.
- Pin 1 is V+ (`VDD_DC_JACK`) and pin 2 is GND. Pigtail wire colours are not standardised, so check against the "− +" silkscreen before the first plug-in.

### Bulk capacitor

- 1000 µF (470 µF at minimum), ≥ 25 V (a full 3S is 12.6 V), low-ESR, 105 °C. Mind the polarity.
- `DC_IN` carries only 10 µF + 0.1 µF of local bulk (C23, C28). A servo current step is therefore sourced through the pack leads and the inlet.
- The board has no free `DC_IN` connector, because both servo ports carry chains. The capacitor therefore goes across V+/GND on the inlet pigtail.
- There it cuts rail sag, but it does not relieve the XH contact itself. Soldering it to `DC_IN` on the board would.

### Pi supply

- A Pololu D24V50F5 (5 V, 5 A, 17.8 × 25.4 mm) drives a USB-C lead to the Pi 4B.
- The Pi wants 3 A peaks. That is about 1.4 A from an 11.1 V pack (15 W before converter loss).
- Where the buck taps the pack line is **open**. Tapping upstream of H1 keeps this current off the 3 A inlet contact.
- The board has its own 5 V buck: an MP8759 labelled "5V-5A … 5V Power for RPi/Jetson nano", feeding the 40-pin header's 5 V pins. The robot powers the Pi from the D24V50F5 instead.

### What the INA219 measures

This was checked against the schematic and the firmware.

- **Wiring.** The INA219 (U2, address 0x42) has IN+ on `DC_IN` and IN− on `VIN`, across R11 (0.01 Ω).
- **What `VIN` feeds.** Only the board's MP8759 buck, and through it the 5 V rail and the 3V3 regulator.
- **Where the servos tap in.** H5 and H6 tap `DC_IN` upstream of R11.
- **What it measures.** Pack voltage at `VIN`, behind the reverse-polarity FET, SW1 and the shunt. That reading does not depend on the servo bus and is valid with torque released. It also measures the current into the board's own logic supply.
- **What it does not see.** None of the servo current. None of the Pi's current, which comes from its own buck.
- **The firmware does not read it.** `board::kPowerAddr` is marked unused, `imu scan` labels 0x42 "(unused)", and battguard reads the servos' register 62 instead.
- **Open:** reading the INA219 in firmware, and getting pack voltage to the Pi for a low-battery shutdown.

## Current: measured budget (issue #77)

The Waveshare wiki FAQ says the bus-servo current "is controlled by a switch, with
a maximum current of 5A for long-term operation". For ST3215s that means "up to 5
servos (ensuring that these 5 servos are not stalled simultaneously)". All of the
servo current crosses H1 (3 A per contact), the AO4407 and SW1.

- **Per servo** (ST-3215-C018 sheet):
  - 2.7 A at stall.
  - 180 mA running with no load.
  - 30 mA idle.
  - Over-current protection turns the output off after more than 2 A for 2 s.
- **The per-port budget is computed from the sim's electrical model**, on the
  committed plant under the deploy servo model, for the two scripted motions
  the design uses: the Gate D walk and the seat-push get-up. Sim figure, not a
  measurement; the bench number with a watt meter on the pack lead is still owed
  ([bringup.md §6](bringup.md#6-staged-hardware-gates)).
- The bus timing is open. Twelve servos take ≈ 3.4 ms of the 20 ms tick ([design record](design-v6/2026-09-13-design-record.md) §4.5); nobody has computed the figure for 17.

The method (`sim/current_budget.py`):

- `walker_env` prices each joint's electrical power as P = max(τω, 0) + K_CU·τ², with `_K_CU` = 3.75 W/(N·m)².
- K_CU is calibrated so that the 2.94 N·m stall draws ~32 W, i.e. 2.7 A at 12 V. Bus current is then ΣP / V per tick, summed per port under the proposed ID map (issue #77).
- `--trace walk` drives the Gate D open-loop walk (8 steps, 1.6 s swing) on `sim/bimo_biped_v6ar.xml`.
- `--trace getup` drives the scripted seat-push (`getup_v6_shoulder.py` config `r5_asdrawn_rom120`, the design's chosen get-up: shoulder 90 → 0°, elbow (0, 0), tuck at hip −120 / knee −130). The variant stands (up_z +1.00, pelvis 0.387 m).
- `--run <run>` drives a trained policy through the referee's six command scenarios, for use once a policy exists for this plant.

Per-port figures (amps at an 11.1 V bus; the 10.5 V landing-floor figures are in the JSON):

| trace | measure | peak | p99 | RMS | mean |
|---|---|---|---|---|---|
| **Gate D walk** (8 steps) | total | 3.34 | 2.53 | 0.54 | 0.36 |
| | port A (9 servos: R leg, neck, R arm) | 2.28 | 0.87 | 0.22 | 0.17 |
| | port B (8 servos: L leg, L arm) | 2.46 | 1.77 | 0.35 | 0.20 |
| | worst joint | 2.46 | 0.65 | 0.22 | 0.17 |
| **Seat-push get-up** | total | 4.54 | 2.13 | 0.64 | 0.37 |
| | port A | 2.27 | 1.07 | 0.32 | 0.18 |
| | port B | 2.27 | 1.07 | 0.32 | 0.18 |
| | worst joint | 1.16 | 0.74 | 0.21 | 0.12 |

The get-up's per-port figures are equal because the chosen script is left/right
symmetric: each port carries one leg plus one arm, and the two legs do the same
work on the symmetric pose.

How to read the numbers:

- **RMS** sizes copper and contacts. Per-port RMS stays under 0.4 A on both traces.
- **The peak** sizes the fuse and the brown-out margin. Neither trace exceeds 3 A on any port, or 5 A on the whole bus. The FAQ's "not stalled simultaneously" is about peaks, and the scripted motions do not stall a servo.
- The shoulder is an STS3215 in both designs; at 74–78 % of stall in the get-up (design record §14.2) it sits close to the servo's 2 A / 2 s overload protection (registers 34–36), and the in-sim 0.22 A per-joint RMS is consistent with being far from trip on the chosen script. **Watch on the bench.**

These figures are from the scripted motions only. A trained walking policy can
load the bus differently — for scale, the same method on the 10-servo
prototype's learned walk (`--run`, never measured on hardware):

| | peak | p99 | RMS | mean |
|---|---|---|---|---|
| whole bus | 6.8 A | 5.0 A | 1.4 A | 0.85 A |
| worst leg | 4.0 A | — | ~0.7 A | — |
| worst joint | 3.0 A | — | — | — |

Two implications, both unset:

- The scripted figures clear both the 5 A board limit and the ~3 A-class per-port connector under the proposed ID map, at the deploy servo model. The trained-policy row does not. Whether the eventual trained walk fits the same envelope is an open question, which is why the budget is per-port and re-runnable: `--run <run>` once a policy for `bimo_biped_v6ar.xml` exists.
- If a later trace puts a port over ~3 A, two options have been named so far. The first is to feed `DC_IN` directly, bypassing the XH inlet and SW1. The second is to keep the scripted motions from loading many servos at once. Neither is chosen — and the choice of inlet, fuse and bulk capacitor stays with the owner.

Reproduce:

```bash
.venv/bin/python sim/current_budget.py --trace walk  --volts 11.1 --out sim/runs/current_budget_walk.json
.venv/bin/python sim/current_budget.py --trace getup --volts 11.1 --out sim/runs/current_budget_getup.json
```

(`sim/runs/` is gitignored; the JSON is a build artifact, not a deliverable.)

## Servo bus

- **The bus.**
  - One bus: UART1 at 1 Mbaud, half-duplex TTL, GPIO 18 RX / 19 TX.
  - The direction is switched in hardware off the TX line (SN74LVC1G125/126 buffers). There is no direction GPIO.
  - The firmware never sees its own transmission. A reply can start microseconds after the last stop bit.
- **Pinout.**
  - H5 and H6 carry the same three nets: pin 1 `DATA`, pin 2 `DC_IN` (V+), pin 3 GND. The silkscreen reads "D V G".
  - The servo's 5264-3P lead numbers its pins the other way: 1 GND, 2 V+, 3 signal (C018 sheet). The middle pin is V+ either way.
- **Chaining.** Every ST3215 has two paralleled ports, so a chain hops from case to case on the stock 150 mm leads.
- **The first lead of a chain carries the whole chain's current.**
  - A Molex-5264-class contact is roughly a 3 A part. No connector datasheet is mirrored here, so that figure is unverified.
  - The chains are split one per port for this reason.
  - With 17 servos and two ports, at least one chain carries nine or more servos, unless a splitter is added. None is specified.
- **Open:**
  - The robot's chain layout: which servos go on which port, and in what order.

### Per-hop lead lengths (from the v6 CAD, ARMS=1)

The spans below are **geometric minima** at the standing pose, measured from
the CAD constants and cross-checked against the built assembly mocks
(`python cad/v6/lead_lengths.py` and its `--assembly` sweep; the hop model and
every routing caveat are in that file's docstring). "loop" is the fold loop
the lead needs to cross the joint named (arc over the joint's ROM at the
cable's own standoff), already folded into "need". Verdicts are against the
150 mm stock lead with a 20 mm plug tail. The board→splitter stub rides on
top of the first hop as a 30 mm allowance — the splitter itself is not
selected.

| hop (chain order, both legs symmetric except where shown) | span | loop | need | buy ~ | 150 ok? |
|---|---|---|---|---|---|
| port (H5/H6) → leg-bus deck slot (via splitter) | 102 | — | 102 | 150 | ✓ |
| deck slot → battery layer (yaw riser mouth) | 48 | — | 48 | 90 | ✓ |
| battery layer → hip yaw | 1 | — | 1 | stock | ✓ |
| hip yaw → hip roll | 61 | 7 | 68 | 110 | ✓ |
| hip roll → hip pitch | 55 | 9 | 64 | 110 | ✓ |
| hip pitch → knee | 110 | 17 | 127 | 170 | ✓ |
| knee → ankle | 110 | 18 | 128 | 170 | ✓ |
| ankle → ankle roll (R / L) | 81 / 87 | 6 | 87 / 93 | 130 / 140 | ✓ |
| port (H5) → neck (upper branch, port A, via deck slot) | 103 + 53 | — | 156 | 190 | ✓ with a short stretch; the 150 mm stock reaches if routed taut over the battery layer |
| shoulder lead leaving the pod (both sides: → R/L shoulder) | 49–101 | — | under 130 | 90–150 | ✓ |
| **shoulder → elbow (both arms)** | **130** | **23** | **152** | **~200** | **NO — does not fit stock** |

What the CAD says about the two named geometry problems:

- **The shoulder→elbow hop is the only hop that cannot ride the stock 150 mm
  lead.** The shoulder servo hangs in the girdle pod at the top of the torso;
  the elbow servo's case rides the upper arm, running up it from the elbow
  axis, so its connector sits 146 mm below the shoulder axis. The lead crosses
  the **shoulder fold, −90°…+200° (290° of sweep)** at the girdle's open
  notch — the notch is cut open to the pod top so the plug exits upward
  (`shoulder_girdle_v6.py:216`) — and then runs down the back of the upper
  arm's web to the window just above the elbow servo's case (`arm_v6.py`).
  There is **no strain relief drawn at the fold**. The 130 mm number is the
  assembly-measured minimum between the two servos' connectors; the 152 mm
  includes the shoulder fold's loop. Plan on a ~200 mm lead for this hop.
- **The lead never crosses the elbow.** The elbow servo turns with the upper
  arm (the forearm forks round its discs), so shoulder plug to elbow plug is
  one piece on one link below the shoulder.
- What is **flagged, not invented**: the yaw carrier has no raceway drawn for
  the yaw→roll hop (straight-line minimum), the leg links carry cable
  *windows*, not routed channels, and the ankle link's "raceway" named at
  `dimensions_v6.py:180` is not drawn. All three are straight-line minima in
  the table.

Sources: the hop model, anchor placements and the measured arm span are
`cad/v6/lead_lengths.py`; placements come from `assembly_v6`'s own mock
chains (the interference gate's placement truth), and the fold/ROM figures
from `dimensions_v6.py` and `docs/design-v6/arms.md` §5.

- **Open (remaining):** the splitter part (both ports feed one, not
  selected); the bus-timing figure for 17 servos.

## Battery protection

The pack has three layers of protection against over-discharge:

1. **The protection board** cuts off at about 3.0 V/cell. This is hardware and does not depend on the firmware.
2. **battguard** (`firmware/components/battguard/`) is the firmware supervisor. It is pure, and its behaviour is asserted on the host in `firmware/host/test_battguard.cpp`.
3. **The operator** lands the robot by 10.5 V. Pack voltage arrives in the 10 Hz telemetry (`vbat`, mV) and from `volt` on the CLI.

Nothing else stops a discharge. The servos' own under-voltage protection sits at 4 V
(C018 sheet), far below the ~9 V (3.0 V/cell) at which a 3S pack is damaged.

battguard's levels are below. The firmware builds the guard with the 3S thresholds;
the 2S constants exist in `guard.h`.

| level | 3S | 2S | what the robot does |
|---|---|---|---|
| ok | > 10.5 V | > 7.0 V | normal |
| warn | ≤ 10.5 V (3.50 V/cell) | ≤ 7.0 V | a telemetry flag only: **you** land it |
| land (`VLAND`) | ≤ 9.9 V (3.30 V/cell) | ≤ 6.6 V | zeroes vx, vy, wz and lift, and ramps the crouch command to 0.60 over 1.5 s |
| safe (`VSAFE`) | 1.5 s after land | | torque off, latched |

These design points carry load:

- **Debounced.** A trip needs 25 consecutive ticks (0.5 s at 50 Hz) at or below the line. Gait transients sag the rail through the pack leads and the inlet, so an instantaneous comparator would false-fire mid-stride.
- **Latched.** An unloaded flat 3S pack rebounds above 10.5 V within seconds of torque dropping. A guard that cleared on recovery would cycle the robot up and down on a ruined pack.
  - To clear it, swap the pack, then run `batt reset` (bench mode) or reboot.
  - While it holds, `home` refuses.
- **Landing stays in distribution.** 0.60 is `walker_env`'s `crouch_range[0]`, the lowest stance the deployed policy was trained to hold. The guard does not cut torque on a standing biped.
- **A dropped bus frame is not 0 V.** The voltage comes from servo feedback, specifically register 62 of the first servo that answers each tick. A tick in which no servo answered counts as "no data".
- **It guards only while armed.** The benched loop reads no servos. On the bench, only the protection board guards the pack.
- **It shares the bus's failure.** Lose the bus and the guard goes blind. The INA219 would remove that coupling, and it is not read.

The advisory landing voltage (`board::kLandVoltage3s` = 10.5 V) and `battguard::kWarn3S` (105 dV) are the same number, and they must agree.

## Control path

| link | rate | role |
|---|---|---|
| ESP32 ↔ servos, UART1 | 1 Mbaud | sync-write targets and read feedback, every 20 ms tick |
| commander ↔ ESP32, Wi-Fi UDP | 20 Hz commands in (port 4210), 10 Hz telemetry out (4211) | the control channel: intent in, state out ([control-channel.md](control-channel.md)) |
| laptop ↔ ESP32, USB-C `USB` | 115200 | flashing, the CLI, `obsdump` |
| Pi ↔ ESP32 | — | **open**; the options are in [sensor-expansion.md §3](sensor-expansion.md#3-perception-the-pi-and-the-head-camera) |

The 50 Hz loop and the policy both run on the ESP32. The radio carries a command,
never joint angles. When the link dies, the robot decays to the trained stand, then
releases torque.

## Diagrams

`docs/wiring-general-driver.svg` shows the 10-servo prototype harness on this board:

- an 850 mAh pack, a GoPro and a BNO085 on P1;
- no protection board, buck or Pi;
- a port and ID layout that does not match the firmware's.

It does not describe the robot, and redrawing it is **open**.

## Bring-up checklist

The full procedure is [bringup.md](bringup.md). In short:

1. Flash over the `USB` port. USB powers the logic but not the servos ([§1](bringup.md#1-flash-and-first-power)).
2. First power through the XH inlet, current-limited ([§1](bringup.md#1-flash-and-first-power)).
3. Set the servo IDs with one servo on the bus at a time, and read the gains back ([§2](bringup.md#2-servo-ids-and-gains)).
4. At the assembled neutral pose, run `middle` per servo, then `cal zero`, `cal dir` and `cal save` ([§3](bringup.md#3-calibrate-zeros-directions-imu-clock)).
5. Run the torque drills: release, reset, and the watchdog decay ([§4](bringup.md#4-torque-drills)).

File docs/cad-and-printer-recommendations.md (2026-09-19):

# CAD software & 3D printer recommendations

*Compiled 2026-07-10, for building the biped (8× STS3215 servos, ~34 cm tall).*
Parts are small — the longest single piece (thigh/shin link) is well under 120 mm — so even a
compact print bed is plenty.*

## CAD software (low-cost / free)

The repo's CAD is **code-based** (`cad/` — build123d/CadQuery Python scripts), so the primary
"CAD software" is already free: a text editor plus a 3D viewer. GUI CAD is still useful for
inspecting STLs, one-off tweaks, and designing around purchased parts.

| Tool | Cost | Best for | Trade-offs |
|---|---|---|---|
| **VS Code + OCP CAD Viewer** (recommended, pairs with this repo) | Free | Editing `cad/*.py` with a live 3D preview of build123d/CadQuery models | Code-first; not a drawing tool |
| **Onshape (free tier)** (recommended GUI) | Free | Full professional parametric CAD in the browser, real assemblies/mates, zero install, runs on anything | Free-tier documents are **public**; fine for an open hobby robot, not for anything private |
| **FreeCAD 1.0+** | Free, open source | Fully local, no cloud, no license risk; imports/exports STEP & STL; huge community | Steeper learning curve, occasional UX roughness vs. commercial tools |
| **Autodesk Fusion (Personal)** | Free for hobbyists | Slickest modeling + built-in CAM/simulation | License limits (10 editable docs, no STEP export on personal tier as of recent changes); Autodesk has repeatedly trimmed the free tier |

**Recommendation:** stay code-first with build123d + OCP viewer for the robot's printed parts
(parametric, diffable in git, regenerates all STLs from one dimensions file), and keep an
**Onshape** free account for assembly sanity checks or quick GUI edits. Choose **FreeCAD**
instead of Onshape if you want everything local/open-source.

For slicing (STL → printer): the slicer comes free with the printer — Bambu Studio, PrusaSlicer,
or the open-source OrcaSlicer (works with nearly every printer, arguably the best of the three).

## 3D printer (reasonably priced)

| Printer | Price (mid-2026) | Build volume | Why / why not |
|---|---|---|---|
| **Bambu Lab A1 mini** ⭐ top pick | **$199–219** | 180×180×180 mm | Best print quality and reliability per dollar; auto-calibration, genuinely plug-and-play; fast (real-world ~500 mm/s class); handles PLA/PETG and TPU (for foot pads). 180 mm bed is ample for every part of this robot. |
| **Bambu Lab A1** | ~$349 | 256×256×256 mm | Same platform, bigger bed — worth it if you want one-piece torso shells or future bigger robots. |
| **Prusa MINI+** | ~$429 kit | 180×180×180 mm | Open-source, fully documented, every spare part purchasable — the repairability/longevity pick. Slower and pricier than the A1 mini. |
| **Creality Ender-3 V3 (KE/SE)** | ~$180–250 | 220×220×240 mm | Cheapest capable option; more tinkering and tuning required — the hours you spend tuning are hours not spent on the robot. |

**Recommendation: Bambu Lab A1 mini ($199–219).** For a robotics project the printer should be a
tool, not a second hobby — the A1 mini is the closest thing to "click print, get part." Add the
AMS Lite (+~$110) only if you want multi-color; it's unnecessary for functional robot parts.

Caveats worth knowing:
- **Bambu ecosystem is partly closed** (cloud-tied firmware; a 2025 firmware-authorization
  controversy). LAN-only mode exists and works. If open-source matters to you on principle,
  that's the case for the Prusa MINI+ despite ~2× the price.
- Whatever you buy, get a **0.4 mm nozzle (stock)**, PLA for structural prototyping, PETG for
  final servo brackets (tougher, slightly heat-resistant near warm servos), and a small roll of
  TPU for foot soles/grip pads.
- Budget ~$25–30 for an M2/M3 screw + heat-set insert assortment; the CAD in `cad/` assumes
  heat-set inserts for anything load-bearing.

## Sources

- [Tom's Hardware — Best 3D Printers 2026](https://www.tomshardware.com/best-picks/best-3d-printers)
- [ADP Industries — Best 3D Printer 2026 (6-printer farm operator)](https://www.adpindustries.com/blog/best-3d-printer-2026/)
- [LayerMath — Prusa vs Bambu 2026, quality/speed/total cost](https://layermath.com/blog/prusa-vs-bambu-2026)
- [BrandChoose — Prusa vs Bambu Lab 2026](https://brandchoose.com/compare/3d-printers/prusa/bambu-lab)
- [Makers101 — Bambu Lab A1 Mini review 2026](https://makers101.com/bambu-lab-a1-mini-worth-it-beginners/)

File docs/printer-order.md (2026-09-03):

# 3D Printer Order (standalone)

*Split out from the robot BOM 2026-07-13. This is the one-time "get a printer +
something to print with" purchase — separate from the robot parts in
[`bom-by-vendor.md`](bom-by-vendor.md). Prices USD, verify at checkout.*

## Decision drivers (why this changed from the A1)

Priorities, in order:
1. **No software lock-in.** The only program that has to run on your computer is
   a *slicer*; it must not chain you to one vendor's cloud/app. (See
   [What runs on your computer](#what-runs-on-your-computer).)
2. **Buy once.** Future projects are expected to run **outdoors** (→ UV-stable
   **ASA**, which needs an **enclosure**) and possibly include **drone frames**
   (→ carbon-fiber nylon **PA-CF**, which needs a **hardened nozzle** + enclosure
   + a filament dryer). So the machine must be an **enclosed CoreXY** that can
   grow into engineering materials — not the open-frame A1, which tops out at
   PLA/PETG/TPU.
3. **Printer as a tool, not a second hobby** — reliable, auto-calibrating,
   minimal tuning.

Leading pick: **FlashForge Adventurer 5M Pro** — an enclosed CoreXY that clears
all three, is highly rated, and is markedly **more open than Bambu** (no
firmware authorization gate, no RFID filament lock, standard Orca-based slicer).
Alternatives and the one thing it *can't* do are covered below.

---

## The order

| Item | Product | Qty | Est. price | Link |
|---|---|---|---|---|
| **3D printer** | FlashForge **Adventurer 5M Pro** — enclosed CoreXY, 220³ mm, 280 °C hotend, HEPA+carbon, 600 mm/s | 1 | **$449** | [FlashForge](https://www.flashforge.com/products/adventurer-5m-pro-3d-printer) · [Amazon B0CH4RG161](https://www.amazon.com/dp/B0CH4RG161?tag=tommwhipple-20) |
| **PLA** 1 kg | 1.75 mm — **prototyping / most robot parts** (stiff, easy). Overture PLA (color selectable on the listing) | 1 | ~$22 | [Amazon B0CPJ4QSPK](https://www.amazon.com/dp/B0CPJ4QSPK?tag=tommwhipple-20) |
| **PETG** 1 kg | 1.75 mm — **final servo brackets** (tough, mild heat). Overture PETG (color selectable) | 1 | ~$25 | [Amazon B0991YSBDG](https://www.amazon.com/dp/B0991YSBDG?tag=tommwhipple-20) |
| **TPU 95A** 1 kg | 1.75 mm — **foot soles / grip pads** (Shore 95A; 500 g would do, 1 kg is the standard roll). SainSmart 95A | 1 | ~$24 | [Amazon B0GTZ79H4X](https://www.amazon.com/dp/B0GTZ79H4X?tag=tommwhipple-20) |
| 99% Isopropyl alcohol (16 oz) | Degrease the PEI plate between prints — finger oils are the #1 adhesion-failure cause | 1 | ~$9 | [Amazon B07NFSFBXQ](https://www.amazon.com/dp/B07NFSFBXQ?tag=tommwhipple-20) |
| **Ready-to-print subtotal** | | | **~$530** | |

> **🛒 One-click cart** (printer + filament + IPA): paste this into a browser to
> pre-load the cart, then *Save for Later* for a wishlist —
> `https://www.amazon.com/gp/aws/cart/add.html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`
> This uses Amazon's legacy bulk-add endpoint; if it doesn't load, use the
> per-item links in the tables instead.

Filament is **brand-agnostic** on purpose — no RFID lock means any reputable
1.75 mm spool works; the pinned listings are proven picks, not requirements, and
**color is selectable on each Amazon listing**. The *materials* (PLA / PETG /
TPU 95A) are what the robot's design calls for. Buy a second PLA roll if you
expect to iterate the prototype heavily (~0.9 kg of plastic per full robot).

> **Buying check:** confirm the listing says **"5M Pro"** and shows the
> *enclosed* body — FlashForge also sells the open-frame base **5M** (~$239)
> under near-identical naming, and the enclosure is exactly what you need for
> ASA/PA-CF. Also watch for **bundles** that pad the ~$449 price with
> filament/accessories. Verified ASIN for the bare 5M Pro: `B0CH4RG161`.

### Already in the box — don't re-buy
The 5M Pro ships with: the **PEI build plate**, **FlashForge glue** (use it as a
release layer under PETG — PETG bonds hard to bare PEI), a **tool kit** (hex
keys, scraper, grease), a **spare quick-swap nozzle**, the **spool holder**, a
**USB stick**, and a **250 g PLA sample** (enough for a first test print, not the
robot). So you don't need glue, basic tools, or a spool holder in the order.

### Recommended tools (not included; strongly advised for this project)

| Item | Why | Est. price |
|---|---|---|
| ~~Digital calipers~~ — **owned** ✅ | Verify printed dimensions against the CAD — the robot has tight tolerances (heat-set bosses, servo mounts, 3.2 mm GoPro slots per `docs/hardware-order.md`) | — |
| Flush cutters | Snip filament and supports cleanly (if not in the included kit) | ~$8 |
| Spare PEI build plate | Dedicate one plate to PETG so you're not constantly re-gluing | ~$20 |
| Desiccant + sealable bags | Keep TPU/PETG dry between prints (both absorb water) | ~$12 |

> **For robot *assembly* (not printing):** the brass heat-set inserts in
> [`bom-by-vendor.md`](bom-by-vendor.md) are installed with a **soldering iron +
> conical/insert tip** (~$20 if you don't already own one). Not needed to print,
> but needed to build.

### Add-ons for when the outdoor / drone projects actually start
*(not needed for the robot — buy when you reach these materials)*

| Item | Why | Est. price |
|---|---|---|
| 0.6 mm **hardened steel nozzle** | Carbon fiber shreds brass/stainless nozzles; required for PA-CF | ~$15–25 (FlashForge offers a hardened option) |
| **Filament dryer** | Nylon/PA-CF (and PETG/TPU) absorb water and print badly wet | ~$40–60 |
| **ASA filament** | UV-stable outdoor parts | ~$25/kg |
| **PA-CF filament** | Stiff, impact-tough drone frames | ~$40–60/kg |

---

## What runs on your computer

The pipeline is **CAD → slicer → printer**, and only the middle piece is new
software on your machine:

- **CAD** — already fully open: your `cad/` is code-based (build123d) → STL/STEP.
  Nothing changes, no vendor involved.
- **Slicer** — the one required desktop app. It turns an STL into machine
  instructions (G-code / `.3mf`). **Slicing is 100% local — no account or
  internet required.** The 5M Pro's official slicer is **Orca-Flashforge** (a
  fork of the open-source **OrcaSlicer**); plain OrcaSlicer also drives it.
- **Transfer** — send the file to the printer by **USB drive** (fully offline),
  or Wi-Fi/Ethernet; FlashCloud is optional, not required.

**Slicer system requirements** (Orca-Flashforge / OrcaSlicer / PrusaSlicer are
all similar; all ship native **macOS Apple-Silicon** builds — you're on a Mac):

| | Requirement |
|---|---|
| OS | macOS 11+ (also Windows 10/11, Linux) |
| RAM | 4 GB min, **8 GB+ comfortable** (CF/nylon geometry is heavy) |
| GPU | OpenGL 3.2+ — integrated Mac graphics fine |
| Disk | ~1–2 GB |
| Internet | Updates/optional cloud only — **not for slicing** |

Any Mac from ~the last 8 years handles this. **Standardize on OrcaSlicer**: it
drives FlashForge, Prusa, Creality, Voron, and even Bambu from one interface, so
your *software* skills stay portable even if you switch printer brands later.

---

## Why the 5M Pro leads (openness first)

- **No vendor gate between your slicer and the machine.** Unlike Bambu (whose
  2025 firmware added a "Bambu Connect" authorization layer that third-party
  slicers must pass through), the 5M Pro takes a standard Orca-based workflow
  over USB/LAN with no handshake, and **no RFID filament lock** — use any spool.
- **Enclosed CoreXY** — the enclosure is the hard requirement for ASA and PA-CF
  (both warp badly in open air). CoreXY is inherently steadier at speed than a
  bed-slinger.
- **Capability** — 280 °C hotend + enclosure + optional hardened nozzle covers
  PLA/PETG/TPU **now** and **ASA + PA-CF** later.
- **Well-regarded & good value** — strong Amazon ratings; HEPA + activated-carbon
  filtration and a silent mode at ~$449, roughly half a comparable Bambu P1S.

### The one limitation to know: no *active* heated chamber

The 5M Pro's enclosure is **passive** (trapped heat drifts to ~40–50 °C). That's
enough for ASA and **small-to-medium PA-CF**, but **large PA-CF or any PC-CF
frames** want an actively heated ~65 °C chamber to stay flat. If serious
large/PC drone frames become the goal, that's the upgrade trigger — and to stay
open, the upgrade path is a **Prusa Core One** (enclosed, open) rather than a
locked-down machine. For everything on the current horizon, the 5M Pro is enough.

### Alternatives, ranked by openness

| Printer | Price | Openness | Notes |
|---|---|---|---|
| **FlashForge 5M Pro** ⭐ | $449 | High | Enclosed CoreXY, Orca slicer, any filament. **The pick.** |
| **Prusa Core One** | ~$949+ | Highest (mainstream) | Fully open PrusaSlicer + standard G-code; the buy-it-for-a-decade open pick. Pricier, slightly slower. Step here if you outgrow the passive chamber. |
| **Voron / Klipper (open CoreXY)** | varies (kit) | Maximum | Fully open firmware, any slicer, self-hosted UI — but it's a build-and-tune project, against the "tool not a hobby" goal. |
| **Bambu P1S / X1C** | $699 / $1,449 | Low | Best out-of-box tuning, but the ecosystem *is* the lock-in (cloud/app default, firmware authorization, RFID). Only if you relax the openness constraint. |

---

## Materials rationale

| Material | Use | Enclosure needed? |
|---|---|---|
| **PLA** | Structural prototyping (cheap, stiff, easy) | No — actually prefers open air |
| **PETG** | Final servo brackets (tough, mild heat resistance) | No |
| **TPU 95A** | Foot soles / grip pads | No |
| **ASA** *(future)* | UV-stable outdoor parts | **Yes** (have it) |
| **PA-CF** *(future)* | Drone frames — stiff, crash-tough | **Yes** + hardened nozzle + dryer |

## Build-volume note

220³ mm is between the A1 mini (180) and the A1/P1S/Prusa (256). It's ample for
every robot part (all < 120 mm). For FPV drone frames it's adequate, but a large
one-piece frame plate may need diagonal orientation or splitting — the 256 mm
machines have more room there. Not a concern for the robot.

---

## Sources
- [FlashForge — Adventurer 5M Pro (official specs)](https://www.flashforge.com/products/adventurer-5m-pro-3d-printer)
- [Top3DShop — 5M Pro: 280 °C nozzle, 220³ build, $449](https://top3dshop.com/product/flashforge-adventurer-5m-pro-3d-printer)
- [SimplyPrint — 5M Pro specs, compatibility & slicer guide](https://simplyprint.io/compatibility/flashforge-adventurer-5m-pro)
- [Tom's Hardware — Adventurer 5M Pro review](https://www.tomshardware.com/reviews/flashforge-adventurer-5m-pro-3d-printer)
- [OrcaSlicer (open-source slicer, cross-brand)](https://github.com/SoftFever/OrcaSlicer)
- [Prusa Core One (open alternative)](https://www.prusa3d.com/product/prusa-core-one/)

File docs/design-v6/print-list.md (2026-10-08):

# v6 print list (2026-09-14)

Generated from `cad/v6/parts_v6.py` (`docs/design-v6/parts_v6_rollup.txt`). PETG 0.4 mm nozzle, 3 perimeters, 30–40 % infill unless noted; every part fits the 220 mm bed. Regenerate STL/STEP with `.venv/bin/python cad/v6/parts_v6.py`; each part module's `__main__` runs its own audits.

| part | qty | g each | orientation | supports | notes |
|---|---|---|---|---|---|
| `pelvis_v7` | 1 | 174 | deck-top-down (v5 pelvis orientation) | **yes**: the two yaw-cell ceilings (the case fills the cell to 0.3 mm, no support-free geometry exists) and the skin window roofs near the housing floor | one print. Boards slide down their deck slots; pack through the deck aperture; neck servo stands in the deck-top well, screwed from below through the aperture. Residual audit findings listed in `pelvis_v7.py`'s docstring — check the sliced preview at the window roofs and the deck-slot edges before printing |
| `neck_collar` | 1 | 20 | flange down, flat | no | slides down over the neck servo standing in the deck well (2.1 mm to the head's horn disc), 4 × M2.5 flat-heads at the flange corners into pilot holes in the deck (`NECK_FLANGE_HOLE_XY`, shared with `pelvis_v7.py`); the servo's own stator screws go up through the deck aperture from below. Split out of the pelvis on 2026-09-14: fused in, its mouth was the print's low point and the whole deck became an island |
| `head_shell` + `head_face` | 1 + 1 | 27 + 7 | shell crown-up (domed top ≥ 45°), face plate flat | no | 4 × M3×6 onto the neck horn from inside before the face goes on; Camera Module 3 on 4 × M2 bosses inside the face; ribbon slot in the base beside the axis. One dome-seam CEILING flag in the audit is believed to be a boolean artifact — verify in the slicer |
| `yaw_carrier` | 2 | 18 | as v5 (`yaw_carrier_print.stl` from `cad/parts.py`) | v5 fins | unchanged v5 part |
| `hip_yoke_v6` | 2 | 25 | on edge like v5 `yoke_roll` + brim | **yes**: pitch horn arm slab over the servo void, roll pad rims / arm plates start in mid-air | roll + pitch clevis as **one print** (default since 2026-09-24): replaces `yoke_roll` + `yoke_pitch_v6` and their 8 × M3×10 flange bolts + 8 heat-sets. 0.5 mm roll-corner relief on the flange top — [hip-yoke-single-print.md](hip-yoke-single-print.md) §6 |
| `leg_link_v6` | 4 | 26 | **standing on the lower fork end** (new: the box's front plate prints as a wall) | brim recommended (round pads meet the bed on a line) | thigh and shin are the same part; 110 mm; closed box section; one 25 mm end-anchored rib at the v5 jog block prints as a short bridge; 2026-09-14 flexion relief cuts (knee 130°) are 40–45° faces, no new supports; 2026-09-24 hip-flexion relief (`LL_HIP_RELIEF`: box top-front chamfer + jog-block trim) — faces up, no new supports |
| `ankle_link` | 2 | 12 | web-down like v5 (`RY_XUP`) | **yes** (CEILING/ISLAND class, same as the yokes) | grips the ankle-pitch servo, forks fore/aft onto the roll servo's discs |
| `foot_L`, `foot_R` | 1 + 1 | 54 | sole down | no | mirrored pair; roll servo drops into the cradle, two tabs with 2 × M2.5 flat-heads each, each tab braced by two fins on its outer face, and a short near-row boss on each case face with 1 × M2.5 |
| `sole_tpu_L`, `sole_tpu_R` | 1 + 1 | 23 | flat | no | **TPU 95A**, glued to the flat plate underside |

**With `ARMS=1`** (the get-up arms, opt-in — `docs/design-v6/shoulder-girdle.md`). The girdle *replaces* `neck_collar`; the rest are additions. Print support is **OrcaSlicer's job** wherever it can do it (Tom, 2026-09-24) — nothing below has modelled supports; the "supports" column is what the slicer must be told.

| part | qty | g each | orientation | supports | notes |
|---|---|---|---|---|---|
| `shoulder_girdle_v6` | 1 | 84 | base down on the deck face | **yes**, build plate only: trapezius-web window tops (34 mm spans), grip-plate rib-relief roofs, bay disc-relief tops | 200 × 58 × 33 mm — centre it on the bed. Both shoulder servos + the neck tube. 10 × M2.5×8 flat-head into deck pilots on the two edge rails; the pack goes in **before** the girdle |
| `arm_upper_v6_L`, `_R` | 1 + 1 | 28 | on its back, web face on bed (`RY_XUP`) | no | open-front U with two end walls, screw-access bore on the outboard face; grips the elbow servo |
| `arm_fore_v6_L`, `_R` | 1 + 1 | 42 | on its back, web face on bed (`RY_XUP`) | **yes**, build plate only: the two elbow-pad undersides (5 mm off the bed) | the elbow fork, an end wall; 12 mm hand knuckle |

Totals (default build, `parts_v6.py` rollup 2026-09-24): 15 PETG + 2 TPU prints, 11 unique STLs, ≈ 592 g PETG + 46 g TPU. Robot ≈ 1.82 kg with 6 × STS3250 + 7 × STS3215 (832 g), a 170 g pack and 180 g of boards and wiring. With `ARMS=1`: ≈ 2.23 kg (11 × STS3215; the girdle replaces `neck_collar`).

Fasteners (from each module's `SCREWS()`; the one-print hip yoke needs no M3×10 flange bolts or heat-set inserts): 24 + 12 M2.5×8 flat-head grip screws (leg links, ankle links), 12 M2.5×8 flat-head in the feet (8 tabs, 4 near-row bosses), 8 M2.5 yaw stators + 4 neck stators + 4 M2.5 neck-collar flange, 8 M2.5 board standoffs + 4 pilot, 2 M2.5 power bosses, 4 M2.5 head face, 52 M3×6 horn + 28 M3×8 idler with washers, 4 M2 camera. Driver access was checked with a 7 mm cylinder on every screw; the exceptions (v5-inherited idler grip counterbores, a few standoff screws close to walls) are listed in the module reports and need a slim driver, not a redesign.

Gates on this set: `cad/v6/check_assembly_v6.py` (ROM interference, every relatively-moving pair, results in `docs/design-v6/cad_rom_check.txt`), the per-part printability audits (`audit_*.py`), and `cad/v6/animate_v6.py` (fly-in along the insertion paths, `cad/v6/renders/assembly_v6_flyin_strip.png`).

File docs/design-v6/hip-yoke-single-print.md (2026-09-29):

# Hip yoke as one print (2026-09-19)

> Dated record: accurate as of its date; the current design is [DESIGN.md](../../DESIGN.md). Evidence cited here for options not taken was removed from the tree on 2026-09-29 and is in git history (`git log --all -- docs/design-v6/<file>`).

Tom: make the link below the hip-yaw carrier — the hip-roll clevis
`yoke_roll` (v5, `cad/parts.py`) and the hip-pitch clevis `yoke_pitch_v6`
(`cad/v6/yoke_pitch_v6.py`), today screwed flange to flange — ONE print.
Result: `cad/v6/hip_yoke_v6.py`, opt-in via `HIP_YOKE_VARIANT=single`
(default `split`, every existing caller unchanged). Not yet the default; two
pre-existing clearance findings it exposed are open (section 6).

## 1. What was merged

| | split (as built) | single (`hip_yoke_v6`) |
|---|---|---|
| parts per hip | `yoke_roll` + `yoke_pitch_v6` | one solid |
| joint | two 4 mm flanges, 4 × M3×10 button head down through `yoke_roll` into 4 × M3 heat-set inserts in `yoke_pitch` (`fasteners.flange_bolts`) | one 8 mm block, bolt columns filled (+356.5 mm³ = exactly the four O3.4 + four O4.1 bores) |
| servo interfaces | roll horn boss + sunk idler pad on X; pitch horn plate + r14 idler hub on Y | **identical** — the merged solid is `yoke_roll() + Pos(0,0,-ROLL_TO_PITCH) * yoke_pitch_v6()`, the v5 geometry itself, not a copy |
| kinematics | `HIP_ROLL_Z`, `HIP_PITCH_Z`, `ROLL_TO_PITCH` 50, `ROLL_AXIS_TO_FLANGE` 16, `PITCH_ARM_REACH` 26 | unchanged; the part is placed at `HIP_ROLL_Z` alone and carries the pitch clevis at −50 in its own frame |
| hip-flexion chamfer (`YOKE_FLEX_CHAMFER`, [design record §11.3](2026-09-13-design-record.md)) | on `yoke_pitch_v6` | kept, via the shared `yoke_pitch_v6.flex_chamfer_wedge()` (also trims the two front bolt fills where the heat-set bores grazed it). `yoke_pitch_v6()` volume unchanged to the last digit after the refactor (9534.799917594863 mm³) |
| envelope | union of the two | the same union — no new material outside either part, so no pair can get *worse* |

Deliberately **not** done: thinning the 8 mm block or trimming the flange
wings that only existed as bolt land (`yoke_roll`'s ±17 mm Y wings beyond the
±12 arm plates; `yoke_pitch`'s ±16 X ends). Both are real savings (~1.6 g per
hip, estimate) but the flange thicknesses set `PITCH_ARM_REACH`, and the wings
are the bridge the arms root into — that is a separate strength decision, and
section 6's flexion finding is *on* the roll flange's front, so its shape
should be decided once, with that.

## 2. Mass (build123d volume, PETG 1.27 g/cm³, × 0.90 print factor as in `parts_v6.py`)

| | volume mm³ | printed g |
|---|---|---|
| `yoke_roll` | 10 037.8 | 11.47 |
| `yoke_pitch_v6` | 9 534.8 | 10.90 |
| **split total** | 19 572.6 | **22.37** |
| **`hip_yoke_v6`** (styled, §7) | 19 905.6 | **22.75** (+0.38) |

Hardware removed per hip (not in the CAD mass; catalogue-typical estimates):
4 × M3×10 button head ≈ 0.9 g each, 4 × M3 brass heat-set (O4.6 × 4–6) ≈
0.35 g each → ≈ 5.0 g. **Net ≈ −4.6 g per hip, −9 g per robot**, and two
part numbers, 8 screws, 8 inserts and one heat-set operation gone from the
build. Whole-robot rollup with the switch: `HIP_YOKE_VARIANT=single
.venv/bin/python cad/v6/parts_v6.py`.

## 3. Print orientation: on edge like `yoke_roll`, supports + brim

The failure this design must not reintroduce: `yoke_roll`'s arms snapped when
printed flange-down, layers stacked *along* the arm, so the cantilever's
bending tension ran across the interlayer bond. The fix (2026-07-30) was to
put the arm length in the bed plane.

In the merged part **both** clevises have their arm length along model Z
(roll arms z −16 → 0, pitch arms z −24 → −50), so any orientation with Z in
the bed plane keeps that tension along the filament for every arm. That
leaves model +X up (`yoke_pitch`'s `RY_XUP`) or model +Y up (`yoke_roll`'s
`RY_ROLL_WALL`). The 45° diagonal, which would let both arm sets lean at
exactly the overhang limit, stands the part on one edge — out.

Either way one clevis prints as walls and the other as horizontal slabs
(roll plates are normal to X, pitch plates normal to Y). A slab arm is sound
against the recorded failure: its layers are planes *containing* the arm
length, so in-plane and out-of-plane bending both load the filament, and the
only interlayer-tension direction (a pull along the plate normal) is the bolt
preload, i.e. compression onto the disc with the servo body as the spacer.
So the choice is print quality, and **+Y up** wins on every count measured
(`check_printability.py`, `RY_ROLL_WALL`):

- first layer **823 mm² (23.0 %)** after the styling pass of §7 (855 mm² /
  23.9 % before it) — the pitch idler arm's r14 hub + riser and the pitch
  flange end lie flat on the bed — vs ≈ 360 mm² (11 %) for +X up;
- height 43.85 mm vs 48.4;
- the roll arms (the ones that broke) print in exactly their proven
  orientation; the 26 mm pitch idler arm (1.6 × a roll arm's root moment)
  prints bed-flat;
- audit: **PASS**, no THIN findings. Slicer supports required for: the pitch
  *horn* arm, a 713 mm² horizontal slab 40.9 mm up over the pitch-servo void
  (its underside is the horn seating face — a support-interface finish on a
  face clamped to a metal disc by four screws; +X up would put the same
  finish on the *roll* horn boss instead, so this is a wash); the roll pad
  rims and arm plates that start in mid-air (as in the `yoke_roll` print);
  the roll flange's −Y face 3.4 mm above the bed (194 mm² island). Brim: a
  44 mm-tall T of 4 mm walls. The horizontal O3.4 bolt-circle bores (the roll
  pads') are a 4 mm-class roof, a note not a fail.

## 4. Checks

Full ROM sweep, `cad/v6/check_assembly_v6.py`, 5 samples per joint, both
variants (verbatim in [`hip_yoke_check_single.txt`](hip_yoke_check_single.txt)
and [`hip_yoke_check_split.txt`](hip_yoke_check_split.txt)).

**Switch off** (post-change baseline): `=> ALL CLEAR (54 s)`, every row
identical to the pre-change run. Default `robot({})` fingerprinted against
HEAD's code: 33 pieces, same labels, volumes and bounding boxes.

**Switch on**: `=> 2 FAIL (54 s)`. The rows that changed:

```
hip_roll     hip_yoke_L             yaw_carrier_L        0.00   0.30    0.0  ok    idler boss rides the bore, volume only
hip_roll     hip_yoke_L~seats       yaw_carrier_L        0.00   1.00  -55.0  ok    minus the disc seats: arms, pads, both flanges get the full buffer
hip_roll     hip_yoke_L             servo_hip_roll_L     0.00   0.00  -55.0  ok    seated on the roll servo discs, must not intersect
hip_roll     hip_yoke_L~seats       servo_hip_roll_L     0.00   0.08  -55.0  FAIL
hip_pitch    thigh_L                hip_yoke_L         271.70   0.00 -125.0  FAIL  thigh grip plates vs the yoke arms
```

With the switch on the check is **stricter** than the split one: the two
pairs where the part is designed to touch (carrier bore, roll servo discs) are
checked whole *and* minus `hip_yoke_v6.disc_seat_zones()` under the full
0.5 mm buffer, and the thigh pair now covers the roll half as well as the
pitch half. Both FAILs reproduce on the **split** geometry (`/tmp` diag, roll
frame, same mock):

| finding | split `yoke_roll` | `hip_yoke_v6` |
|---|---|---|
| thigh at hip −125 | ∩ yoke_roll **271.70 mm³**; ∩ yoke_pitch 0.00 (0.70 mm) | ∩ hip_yoke 271.70 mm³ |
| thigh, fine sweep | −114: 2.41 · −115: 1.84 · −116: 1.32 · **−117: 0.78** · −118: 0.24 · −119: 3.87 mm³ · −120: 29.59 mm³ | same solid |
| minus seats vs roll servo, ±55 | 0.00 mm³, **0.08 mm** | 0.00 mm³, 0.08 mm |

So: **hip flexion clearance to the thigh is not worse than before — it is
the same solid** (the pitch-half chamfer still gives 0.70 mm at −125), but
the −125° figure was only ever proven against `yoke_pitch`; `thigh_{s}` vs
`yoke_roll_{s}` was never in the v6 PAIRS list.

Re-run after the styling pass of §7: **the same two FAILs and nothing new**
(`=> 2 FAIL (57 s)`). The −125° row reads 273.85 mm³ rather than 271.70 —
accounted for to the mm³ in §7.4.

## 5. Exports and figures

- `cad/v6/stl/hip_yoke_v6.stl`, `cad/v6/step/hip_yoke_v6.step` (from the
  module's `__main__`, which also runs the audit and the mass comparison)
- `cad/v6/renders/hip_yoke_v6.png` — iso / bottom / back; the bottom view
  shows the solid cross where the bolt land was
- `cad/v6/renders/assembly_v6_flyin_hipyoke_strip.png` — fly-in with the
  switch on (`HIP_YOKE_VARIANT=single MUJOCO_GL=cgl cad/v6/animate_v6.py`;
  31 pieces in 14 groups; the yoke takes the pair's path, lowered onto the
  pitch-servo discs from above in group 6; the .mp4 is gitignored)

## 6. Open items (design decisions, not taken here)

> **Resolved 2026-09-24 — `hip_yoke_v6` is now the DEFAULT** (Tom: *"didn't we
> combine the two parts of the hip joint?"* … *"yes, go ahead. We need to re-run
> the getup with these arms anyway."*). Items 1–3 below are closed as follows;
> item 4 (bench) stands.
>
> **Item 2 — roll servo corner, 0.08 → 0.58 mm at ±55° roll.** A 0.5 mm relief
> (`hip_yoke_v6.ROLL_CORNER_RELIEF`) on the roll flange's top, *only* across the
> servo case's own thickness (x −17.15..+18.98, its idler boss to its horn rib,
> ±0.5), so both roll arm plates' root fillets — the roll clevis's load path —
> are untouched and `ROLL_AXIS_TO_FLANGE` / `PITCH_ARM_REACH` / every v5 part
> stay as they were. Servo interfaces IDENTICAL, printability PASS, −0.74 g.
>
> **Item 1 — hip flexion: −125 was never reachable; the ROM is now −120.**
> Measured, the clash is not the thigh's grip top but its **front wall** (the
> leg link box's top edge, thigh-local x 11–16, z −33..−41), meeting the roll
> flange's front from −118.4° in *both* variants. Clearing −125 would have meant
> a 5.7 mm cut straight through that 2.6 mm wall (option c) — the thigh's
> sagittal-bending flange where the hip moment peaks, and the same hole under
> the knee on the shin — or thinning the **roll horn arm's root** from 3.0 to
> ~1.1 mm (option b). Option a was tested in sim first: the get-up **needs the
> tuck at ≥ 119°** (stands at −119/−120/−121/−125, and at −118/−117 not once in
> 84 variants incl. broader ankle/knee/push-time grids —
> `getup_search_r5_asdrawn_hip*.txt`). So: `leg_link_v6` gets `LL_HIP_RELIEF`
> (a 3.5 × 4 mm chamfer on the box's top-front edge + the idler jog block's
> sliver forward of the servo case trimmed), which takes the thigh to **0.70 mm
> at −120°**; past that the thigh's own servo case is next, so −120 is the
> limit without redesigning the joint. `ROM["hip_pitch"]` −125 → **−120**. The
> get-up at the real limit (plant capped at −120): 2/12 variants stand, both
> 6/6 robust. The pair `("hip_pitch", "thigh", "yoke_roll")` now also runs in
> the legacy split sweep, so this can't hide there again.
>
> **Item 3 — promoted**: `HIP_YOKE_VARIANT` defaults to `single`; the parts
> rollup and `print-list.md` carry `hip_yoke_v6` × 2 in place of `yoke_roll` +
> `yoke_pitch_v6` (−2 part numbers, −8 M3×10 flange bolts, −8 heat-sets).
> `HIP_YOKE_VARIANT=split` still builds the bolted pair.
>
> **Still open:** the *walk* plant's `hip_pitch_range` is still (−125, 90). The
> walk policy's action scaling is tied to that range, so bringing it to −120 is
> a training-side change for the next night round, not a CAD one.

1. **Hip flexion is limited by the ROLL flange, at ≈ −117°, in both
   variants.** The thigh's grip top reaches the roll flange's front face
   (x 19.8..24.5, full ±17 width, z −20..−13 — the flange front *and* the
   horn-arm root) from −119°. The `ROM["hip_pitch"]` lower bound of −125 and
   the plant regenerated from it (§11.3) rest on the pitch-half check alone.
   Options: (a) pull the ROM back to −117 (buffer met at 0.78 mm) and
   regenerate the plant; (b) relieve the roll flange's front — but the
   overlap runs into the horn-arm plate root, which is the roll clevis's
   load path, so this is a strength call, best made together with the
   wing-trim in section 1; (c) shorten the thigh's grip top. Whatever is
   chosen, `("hip_pitch", "thigh_{s}", "yoke_roll_{s}")` should join the
   split PAIRS list so the gate covers it.
2. **Roll flange top face vs the roll servo's output-end corner: 0.08 mm at
   ±55° roll.** `ROLL_AXIS_TO_FLANGE` 16.0 was justified against the bay-wall
   bottoms at ±25°; the 2026-08-03 widening to ±55° made the servo's own case
   corner (r = √(12.36² + 10.11²) = 15.97) the binding feature. The mock is
   square-cornered where the real case is radiused, so the physical gap is
   larger, but it fails the 0.5 mm rule and the split check never listed the
   pair. Options: 0.5 mm off the flange top (moves `ROLL_AXIS_TO_FLANGE`,
   hence `PITCH_ARM_REACH`), or accept with a measured corner radius.
3. Promote the switch to default (parts_v6 rollup, print list, BOM: −8 M3×10,
   −8 heat-sets, −2 part numbers) once 1 and 2 are decided; then the
   `yoke_roll` / `yoke_pitch_v6` rows in `print-list.md` become this part.
4. Bench: print one, confirm the supported horn-seating face of the pitch
   horn arm seats flat on the disc (support interface Z gap 0.2 mm), and
   that the on-edge part with a brim does not tip during the pitch horn slab.

## 7. Styling pass (2026-09-19)

Tom, on the part above: *"This 'merged' part just looks like the two parts are
just slapped together... functional but not pretty. Let's make it more organic
and streamline all of the sharp corners as much as possible."*

He is right, and section 1 says why: the merged solid was a **pure boolean
union**, so wherever the two flange footprints disagreed it kept a bare step.
They disagree everywhere, because the two clevises are rotated 90° to each
other:

| | fore/aft (x) | across (y) |
|---|---|---|
| roll flange (z −20..−16) | −23.95 .. 24.45 (48.40) | ±17.00 (34.00) |
| pitch flange (z −24..−20) | ±16.00 (32.00) | −20.40 .. 23.45 (43.85) |

In plan the 8 mm block is a **plus sign**: the roll flange overhangs fore and
aft by 8.45 / 7.95 mm (a bare downward ledge at z −20), the pitch flange
overhangs on ±y by 6.45 / 3.40 mm (a bare upward ledge on the same plane).
That plane — the old bolted joint — is what read as "slapped together".

### 7.1 What the blend actually is

Everything is in `cad/v6/hip_yoke_v6.py`; `fused()` is the old solid, kept as
the A/B reference, and `hip_yoke_v6()` is `fused()` + the styling pass.

1. **The waist.** A cove (`R_WAIST` 2.75) on each of the four reentrant lines
   at z −20: the roll flange's underside into the pitch flange's two side
   faces, and the roll flange's two side faces into the pitch flange's top.
   The step becomes a continuous curved transition from one footprint to the
   other — this is the blend, and it is why the block no longer reads as two
   plates stacked.
2. **The silhouette.** The block's six vertical corners at `R_CORNER` 4.5
   (the pitch flange's front two are already the flexion chamfer's diagonal,
   which gets `R_PLATE` 2.0), every horizontal flange rim at `R_BROW` 1.0,
   and the arm plates' outline corners at `R_PLATE` 2.0.
3. **Arm roots** — structural, not cosmetic; this is the cantilever that
   snapped in the field. `R_ROOT` 2.5 where there is room: both roll plates'
   side roots, the pitch horn arm's three roots, the idler riser's three.
   `R_ROOT_SERVO` **0.6** on the two roots that face a servo case: the roll
   servo's corner sweeps 0.08 mm over the roll flange top at ±55° of roll and
   the bay walls run 1.0 mm off each roll arm's inner face, so a full-size
   fillet there would spend clearance the joint does not have.
4. **Shoulder tapers**, `leg_link_v6`'s corner-cut idiom: each arm plate is
   12 mm half-wide over a r 10 pad, so the two corners where the rectangle
   oversails the pad carry nothing. Taper 1.7 × 3.0, apex 0.3 mm outside the
   pad radius so no servo interface is touched. **Not on the roll idler
   arm**: behind its sunk pad (`ROLL_IDLER_PAD_SINK` 1.35 of 3.0) that plate
   is already a 1.65 mm floor, and tapering its shoulder too left a feather
   edge where the cut ran tangent to the sink — `check_printability` caught
   it as 2.6 mm² of wall under 0.85 mm, which is a wall this part is not
   allowed to grow. Its shoulders stay square.
5. **`_flex_relief()`**, last: the flexion chamfer's own plane re-cut across
   the flange band, so the front cove dies into the chamfer instead of
   bulging past it into the thigh's sweep.

Print orientation is unchanged (`PRINT_ORIENT` / `RY_ROLL_WALL`, on edge,
model −Y on the bed) and edges **lying in the bed plane are chamfered, not
rounded** — a fillet there starts horizontal at the first layer, an
unsupported 90° overhang around the part's own bed contact, where a chamfer
is a printable 45°. First-layer contact is still 823 mm² and
`check_printability` still passes.

### 7.2 The fillet helper, and why it is one edge at a time

`_round_edges()` walks `_groups()` — (name, radius, predicate) — re-querying
the edges from the *current* solid each time, so nothing holds a stale edge
reference. Each predicate pins **both** faces' planes (`_on(e, y=..., z=...)`),
never one: a fillet leaves a tangent line one radius away on each face, and a
one-plane test happily re-selects that line on the next group, which cannot be
filleted and shows up as a phantom failure. Each edge gets its target radius,
then 0.7 / 0.5 / 0.35 / 0.2 of it, then the same ladder as a **chamfer**
(`leg_link_v6`'s fallback); an edge that survives none of it is skipped **and
reported** with location and length.

Two things were measured rather than assumed:

- **Group fillets are out.** Filleting a group in one call blends the corners
  where its edges meet and is the prettier result, but on this solid it does
  not merely fail — OCC **segfaulted** on the four pitch-flange bottom rims
  (exit 139, no STL, no traceback). A crash cannot be caught in process, so
  the group path was deleted. `HIP_YOKE_TRACE=1` prints a flushed breadcrumb
  per edge for the next time this happens.
- **Order matters, and the order is corners-then-rims.** Rims first leaves
  each 4 mm corner trimmed to 1.2–2.6 mm between two blends and OCC then
  refuses it at every radius: 4 of the 6 block corners were lost that way.
  Corners first costs only the corner *arcs*, which a later group picks up.
  `R_BROW` is 1.0 rather than the 1.4 a 4 mm flange could take, for the same
  reason: at 1.4, four of the block's rims were dropped outright.

### 7.3 Edges left unrounded (5)

| edge | at | length | why |
|---|---|---|---|
| block corner arcs ×2 | (−21.92, −14.97, −20.00) and (−21.92, −14.97, −16.00) | 5.50 mm | where the roll flange's rear −y corner blend meets the top and waist planes. Refused as fillet and as chamfer at every radius down to 0.2 mm. Cosmetic: the corner itself is R4.5, this is the crease around it. |
| roll arm plate corners ×2 | (−20.95, ±12.00, −7.70) | 15.40 mm | the roll **idler** arm's two inner-face corners. Their outer twins at x −23.95 are rounded, so the plate reads slightly one-sided. Both faces here are free space (1.0 mm to the bay wall), so this is finish, not fit. |
| pitch idler hub rim | (−4.79, −20.40, −63.16) | 53.76 mm | the r14 hub's outer rim — the part's **bed contact face**. Refused everything, including chamfer-first. Leaving it square is the benign failure: it is the first layer, and a sharp rim there is what the brim wants anyway. |

Deliberately **not** attempted, and not in the list because they are not
failures:

- **the roll pads' rims.** With the bolt circle at r 7 (`BCD` 14), an M3
  head's edge lands at r 10.0 — the pad's own radius. Any round there
  undercuts a fastener seat.
- **the pitch horn plate's inner corners** (y 20.45): that face is the horn
  **disc seat**.

`check_interfaces()` is the hard gate on all of that: it intersects both the
raw and the styled solid with `_interface_zones()` (r 10.2 cylinders on all
four disc axes — pads, bolt circles, bosses, sunk idler pad, centre reliefs)
and requires the volumes to match. They do, to 6 × 10⁻⁴ mm³ of 3908.9557.

### 7.4 Mass, and every clearance that moved

| | volume mm³ | printed g |
|---|---|---|
| `fused()` (as shipped at `afd4daf`) | 19 929.1 | 22.78 |
| `hip_yoke_v6()` styled | 19 905.6 | 22.75 |
| | **−23.5** | **−0.027** |

The blends add 116.0 mm³ (coves and root fillets), the rounds and tapers take
139.5 mm³ back.

Clearances, measured in the yoke's own frame against the same mocks
`check_assembly_v6` uses (link 1 = carrier + roll servo rotated by −hip_roll,
link 3 = thigh + pitch servo rotated by +hip_pitch; the probe reproduces the
gate's numbers exactly):

| | fused | styled |
|---|---|---|
| roll servo vs yoke−seats, ±55° | 0.076 mm | **0.076 mm** |
| bay walls vs yoke−seats, ±55° | 1.000 mm | **1.000 mm** |
| thigh, first contact in flexion | −118.40° | **−118.40°** |
| thigh at −117° | no contact, 0.700 mm | **no contact, 0.700 mm** |
| thigh at −121° | 78.71 mm³ overlap | **77.31 mm³** (better) |
| thigh at −125° | 271.70 mm³ overlap | **273.85 mm³** (+2.15) |

(The constant 0.700 mm is the thigh grip plate vs the yoke arm gap, which
does not vary with the angle; deep flexion shows up as overlap volume, which
is why the table reports both.)

The one number that moved the wrong way is −125°, by 2.15 mm³ on 271.70 —
**+0.8 %, entirely the horn arm's root fillet**. Located exactly: at −125°
the only styling material inside the thigh is the 3.71 mm³ lump at
x 21.45..24.45, y 12.00..14.50, z −16.00..−13.50, which is the R2.5 fillet at
the roll **horn** arm's +y root; at −119° and −121° *no* added material is
inside the thigh at all (0.00 mm³). So the pose that got worse is 7° past the
part's own hard contact at −118.40° and 6° past the gate's first FAIL, in a
pose where both the old and the new solid are already deep inside the thigh —
and the cost is the root fillet on the arm that snapped in the field, which
is the one blend in this pass that is not cosmetic. It is called out here
rather than quietly traded; if section 6's open item 1 is settled by
relieving the roll flange front, this goes with it.

## 8. One plate, not two stacked ones (2026-09-19)

Tom, on the styled-vs-fused A/B in FreeCAD: *"not much difference... at least
combine the two former baseplates into one."*

Correct, and §7's rounding could not have fixed it. **The two flanges are a
plus sign in 3D, not in plan.** The roll flange owns the top band (z −20..−16)
and runs x −23.95..24.45 by y ±17; the pitch flange owns the bottom band
(z −24..−20) and runs x ±16 by y −20.40..23.45. On every side of the old
bolted plane one flange oversails the other and leaves a ledge, and no amount
of edge rounding removes a ledge — it only rounds its lip.

### What the ROM allows

Each candidate fill was measured **on its own**, against the thigh, the pitch
servo, the roll servo and the yaw carrier, over the whole ROM of both hip
joints, before any of it was drawn:

| notch | fill | worst overlap, whole ROM | nearest miss |
|---|---|---|---|
| rear, bottom band | 1081.2 mm³ | **0.00** | 4.26 mm (roll servo @ +55) |
| +y, top band | 825.6 mm³ | **0.00** | 7.50 mm (roll servo @ 0) |
| −y, top band | 435.2 mm³ | **0.00** | 5.58 mm (thigh @ −118) |
| rear hull corners | 313.2 mm³ | **0.00** | 8.33 mm (carrier @ −55) |
| **front, bottom band** | 1482.1 mm³ | **47.4 mm³ into the pitch servo @ −118.4, ~411 @ −125** | — |

So three of the four ledges are simply free, and they are now filled: the
flange band is **one prismatic outline through the full 8 mm** from the rear
face forward to x = +16, on all three of those sides.

### Why the front keeps its step

The front is the corner the hip-flexion chamfer exists for, and it refuses
every form of filling:

- **square fill** — 47.4 mm³ into the pitch servo at −118.4°, ~411 at −125
- **sloped ramp** leaning away from the sweep (the obvious dodge: lean the
  face back so the thigh passes outside it) — still 189 mm³ at −125
- **chamfering the roll flange back** instead of filling under it, which would
  cost mass rather than add it — not available: the material that would have
  to come off is the roll **horn arm's own root**, the load path that broke in
  the field

So the front step stays, and `_flex_relief()` carries the chamfer plane across
the whole band there so it reads as the deliberate relief it is.

### Cost

| | volume | mass |
|---|---|---|
| fused (raw union) | 19 929.1 mm³ | 22.78 g |
| §7 styled | 19 905.6 mm³ | 22.75 g |
| **one plate, styled** | **22 866.5 mm³** | **26.14 g** |

**+3.39 g per hip, +6.8 g the pair** — 0.4 % of the 1.65 kg robot, at the hip,
close to the CoM.

### It did not cost clearance — it bought some

Every gate is unchanged or better than the *raw fused* part:

| | fused | one plate |
|---|---|---|
| roll servo vs yoke−seats ±55° | 0.076 | 0.076 |
| bay walls ±55° | 1.000 | 1.000 |
| flexion first contact | −118.398° | **−118.398°** |
| thigh @ −119° | 3.870 mm³ | **3.451** |
| thigh @ −121° | 78.706 mm³ | **72.525** |
| thigh @ −125° | 271.698 mm³ | **268.752** |

`check_interfaces()` 3908.9557 → 3908.9551 mm³ (IDENTICAL). `check_printability`
PASS, and the first-layer contact **grows 823 → 1048 mm²** (29.3 % of the
bbox), which is a straight win for a 44 mm-tall part on a brim.
`HIP_YOKE_VARIANT=single check_assembly_v6.py` → the same 2 pre-existing FAIL
rows, nothing new.

### One OCC trap, recorded

Cutting `_flex_relief()` only *after* the blends — where it belongs, per §7 —
hits a boolean glitch once the one-plate fill is present: the cut returns the
**right volume** but leaves the **tool's own envelope** behind as material, so
the part's bbox silently grows to the wedge's margins (x to RX1+2, y to
PY0−1..PY1+1). That is 2 mm of phantom flange sitting directly in the thigh's
path, and *volume alone would never have caught it* — only the bbox did. The
fix is to cut once before the blends and once after; the second cut still
earns its keep, taking the 3.1 mm³ of front waist cove that blends out past
the chamfer plane. **Check the bbox, not just the volume, after every boolean
on this solid.**

### Edges still not rounded (6)

The five from §7, plus two new ones created by the fill: the front step's own
top-rim ends at (16.00, −18.70, −20.00) and (16.00, 19.22, −20.00), 3.40 and
4.45 mm, where the new plate outline runs into the surviving front ledge.

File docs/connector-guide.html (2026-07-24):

Biped harness · 2026-07-16

# The four connectors on the robot

Everything plugs together with these. Only two things are bought as cables (the yellow chips say which BOM line); the rest ships attached to parts already on the order. Lengths shown are the worst-pose routed paths measured in cad/dress.py, so slack for flexing is already counted.

## 3-pin servo bus lead

Molex 5264 family · 2.54 mm pitch · housing ≈12×6 mm

ST3215 servo end face with the dual connector port slot

Idler-side case face (the face opposite the horn, where the idler disc sits): both ports live behind this slot, side by side next to the idler disc, electrically identical. (Clarified 2026-07-24 — "end face" here means the idler FACE of the case, not the cable-end of the case; the CAD SV_CONN constants model this position.)

Servo lead plugged into the driver board's S V G port

The same lead plugged into the board — silkscreen reads S V G

Pinout

1 GND 2 V+ (battery) 3 DATA

Where

Every hop of both daisy chains: board → hip roll → hip pitch → knee → ankle. Each ST3215 has two internally-paralleled ports, so chaining is case-to-case with no splitters. The white shell has a friction lock — it only seats one way.

You need

8× 150 mm leads ship with the servos (6 used, 2 spare). Buy 2× ≥200 mm extensions for the hip-roll→hip-pitch hop — 170 mm at the worst pose, the one place stock leads can’t reach. BOM item 19

## XT30 — battery power

Amass XT30U · 2 mm gold bullets · shell ≈18×10 mm

Amass XT30 connector, yellow nylon with two gold bullet sockets

The yellow wedge — keyed, impossible to reverse. XT60 is the same shape 40% bigger; don’t mix.

Pinout

+ 11.1 V − GND

Where

The Tattu pack’s lead ends in one. It mates the pigtail, which runs through the inline power switch into the board’s screw terminal (or a DC 5.5×2.1 barrel plug — the board takes either, photo below). Rated ~15 A continuous against our ~10 A transient budget.

You need

1× pigtail + inline switch + heat-shrink, 20 AWG or thicker. The routed run is only ~30 mm, so any short pigtail works. BOM item 20

## JST-SH 4-pin — IMU

STEMMA QT / Qwiic · 1.0 mm pitch · housing ≈6×4 mm

JST-SH 4-pin plug closeup

Grain-of-rice class — by far the smallest plug on the robot. Pull the shell, never the wires.

BNO085 breakout with JST-SH jacks on two edges

BNO085 breakout: a JST-SH jack on each end, either one works

Pinout (Adafruit standard colors)

3V3 GND SDA→21 SCL→22

Where

BNO085 IMU → ESP32 I²C. The driver board has no JST-SH jack, so the cable’s other end is four male jumper pins onto the board’s GPIO header (21 SDA / 22 SCL, shared with the OLED — no address conflict).

You need

1× Adafruit 4209 (JST-SH → male jumpers, 150 mm — ample; the IMU sits on the deck beside the board). BOM item 21

## Already on the board

Waveshare Servo Driver with ESP32 · 65×30 mm

Driver board: two S V G bus ports, DC barrel, USB-C

Two S·V·G bus ports (one per leg), DC 6–12 V power entry, USB-C

Nothing to buy here

The two white ports are the same electrical bus — one per leg is purely cable routing. Power enters at the barrel/terminal block on the left edge. The USB-C is flashing and tethered debug only; operating the robot never needs it (any data-capable cable, skip if owned).

Bring-up reminder

Servos ship as ID 1 — plug them in one at a time to assign IDs 1–8 via the web UI before chaining (two same-ID servos won’t enumerate).

## Measured hop lengths

worst pose over full ROM, slack loops included

Hop (per leg) | Worst routed | Lead
board → hip roll | 33 mm | stock 150 mm, coil excess in the tower
hip roll → hip pitch | 170 mm | ≥200 mm extension — crosses two joints, longest at knee flexion
hip pitch → knee | 111 mm | stock 150 mm (~35% slack)
knee → ankle | 82 mm | stock 150 mm (worst at ankle −40°)
battery → board | 30 mm | XT30 pigtail + switch
IMU → board | <50 mm | JST-SH jumper cable, 150 mm

Photos: Waveshare product pages (ST3215, Servo Driver with ESP32), Adafruit (4209, BNO085), BerryBase/Amass (XT30) — embedded for private reference. Full harness spec: docs/wiring.md · itemized purchases: docs/bom-sourced.md items 19–21 (commit bffeb25).

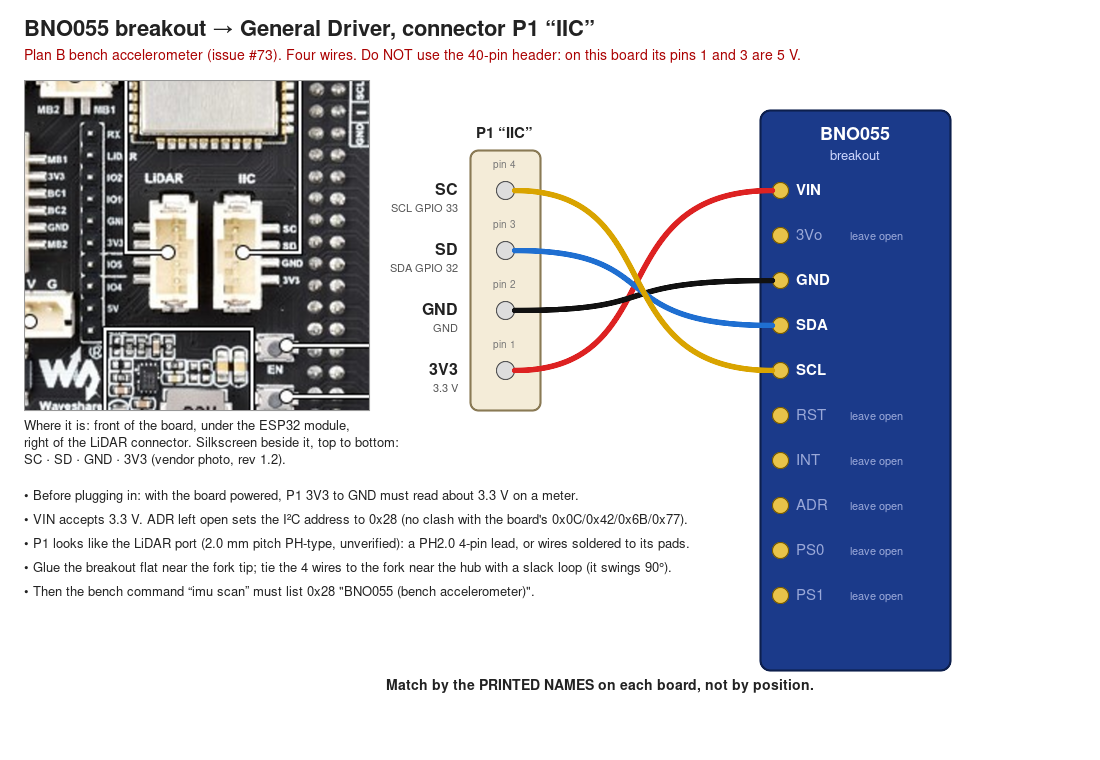
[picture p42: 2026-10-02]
experiments/plan-b-bench/figs/bno055_wiring.png

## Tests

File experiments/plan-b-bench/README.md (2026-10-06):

# Plan B bench (issue #73)

Does raising an STS3215's position-loop P about 4× make it about 4× stiffer
without buzzing? [DESIGN.md §4](../../DESIGN.md) and §13, steps 0 and 1, and
the design record's §14 say why it matters. Everything specific to this
experiment is in this folder.

| file | what it is |
|---|---|
| `gain_bench.py` | the bench tool: `scan`, `read`, `park`, `stiffness`, `hold`, `stance`, `report`, and `--rehearse` against a simulated servo. It drives the firmware's bench CLI over the tether. The procedure is in [docs/servo-map.md](../../docs/servo-map.md) §4 |
| `plan_b_rig.py` | the rig's CAD: bracket, stiffness lever, hold lever with its lid, and stop pin. Running it writes `stl/`, redraws `figs/` and runs the fit checks |
| `plan_b_rig_v3.py` | rig v3, held on both faces: a bracket that is leg_link's two-face case grip in a closed box, and a fork lever on the horn and the idler disc. M10 bolt weights go through the fork's floor at r 40 / 70 / 100, head under the floor. Running it writes `stl/plan_b_v3_*.stl` and runs the fit checks, including the fork and weights swept from level to hanging |
| `stl/` | the rig's printable parts, written by `plan_b_rig.py` and `plan_b_rig_v3.py`; don't edit them by hand |
| `figs/` | the rig's side view and render, drawn by `plan_b_rig.py` |
| [2026-09-30-plan-b-rig.md](2026-09-30-plan-b-rig.md) | the rig: loads, parts, seating, fit checks, procedure |
| [2026-09-30-plan-b-bench.md](2026-09-30-plan-b-bench.md) | session 1: the bench servo's registers and the unloaded P ladder |
| [2026-10-01-plan-b-bench.md](2026-10-01-plan-b-bench.md) | session 2: loaded stiffness (bottles) and hold with a rigid inertia (C-clamp); friction-free k ×3.5 at P 128, ×4.8 at P 160, but P 160 limit-cycles with the clamp; P ≤ 128 / D 32 quiet at hold, sweeps shake from P 96 up; incidents |
| [2026-10-02-oscillation-research.md](2026-10-02-oscillation-research.md) | research: how STS3215 users (LeRobot, Open Duck Mini), Dynamixel humanoids and the control literature deal with the high-P limit cycle, and which remedies the registers allow |
| `2026-10-01/` | session 2's run scripts (incl. `hold_clamp.py`) and per-state / per-pass summaries |
| [2026-10-02-plan-b-bench.md](2026-10-02-plan-b-bench.md) | session 3: hold on the v3 rig (fork, both-face grip, washer weights); plumb from Tom's string; P ≤ 128 / D 32 quiet and settles, P 160 limit-cycles hanging, sweeps clean only to P 96; D 0 smoother; an accelerometer finds the ~15 Hz shaking; P 96 / D 0 shakes like stock at walking speeds; the firmware's own 50 Hz streaming is fine |
| `2026-10-02/` | session 3's run scripts (`sweep_smooth.py`, `stream50.py`, `retarget_analysis.py`) and per-pass summaries, incl. the calibration and the accelerometer check |
| `<date>/raw/` | **the raw measurements** of every run: `session.log` (every CLI line sent and received), `console*.txt` (the operator's view; its first line is the run's exact parameters), and the per-run JSON with every sampled window. Session 3's JSON includes the 500 Hz accelerometer traces. Videos and their `.pts` / `.camlog` sidecars are not in git |
| `summarise_raw.py` | rewrites the summaries the run scripts did not write (session 1, runs A and B, the 10-02 calibration and accelerometer check) from `raw/`, with `gain_bench`'s own statistics |
| [REPRODUCE.md](REPRODUCE.md) | **how to rebuild the bench and repeat all three sessions**: hardware, the two rigs, loads, firmware per session, calibration, safety rules, every run's command and parameters, and the metrics' definitions |

Its offline tests are `tests/test_gain_bench.py`. They stay in `tests/`,
because the pre-push gate collects that folder.

**Data:**
- The scripts write raw data to `hw_sessions/<date>/<run>/` (gitignored).
- After a session, copy its logs, consoles and JSON (not video) into
  `<date>/raw/<run>/` here, and write any missing summary.
- Each session's record goes here as `<date>-plan-b-bench.md`.

## Status and open items (2026-10-06)

**What the bench has shown** (details in the dated records):
- Stiffness rises with P: **3.5 ± 0.4×** at P 128 and **4.8 ± 0.6×** at P 160,
  from bottles with D = P.
- P 160 limit-cycles with a rigid inertia on both rigs.
- **The bench's best candidate is P 96 / D 0.**
  - At walking speeds it shakes about as much as stock P 32 (57–111 mg against
    52–85). The same holds through late goal changes and under the firmware's
    own 50 Hz streaming.
  - It does shake more on slow 100 steps/s sweeps.
  - Its stiffness is ≈ 2.8–3.6× (clamp probes), below the sim's 3–4× target.

**Decided:**
- Tom ordered 2 × STS3250 on 2026-10-02 for the hip rolls, the placement the
  sim needs at a 2.8× STS3215 (design record §14.4a).
- **When they arrive:** run the same v3 rig, weights, accelerometer, firmware
  and ladder (bottle stiffness, hold, sweeps A/C/fast, stream50,
  accelerometer), with an ID off the bus map (e.g. 31), for a direct
  comparison with the STS3215 data here.
- **Check first:** that the fork fits the STS3250's horn. Measure the
  accelerometer's distance from the axis and the weights' radius.

**Not yet carried into the design:**
- `DESIGN.md` §4/§13, `docs/servo-map.md` §4 and `firmware/main/servo_gains.h`
  still list the factory P/D 32/32 on every servo.
- They change when Tom picks the gain. The record of that choice should cite
  these sessions.

**Not yet measured:**
- **P 96 / D 0:** its stiffness with bottles (Tom: later), and its hold test.
  Both are carried over from D 32 or from clamp probes today.
- **The loads:** the mass of a bottle, of the washer weights and of the clamp;
  which fork holes the washers were in; the accelerometer's distance from the
  axis.
- **A true leg-sized inertia:** the salt cup, or 0.25 kg rigid at 100 mm.
- **The research note's bench questions:** hold at P 128 / D 8 and D 16; P 160
  with dead zone 2–3; register 21 written with the lock at 1 (gain scheduling).
- **Streaming:** the "matched" mode needs rework; the robot rule's 2–3° lag is
  unchecked against the sim's actuation model.
- **Unidentified:** the speed-locked 12.7 / 25.4 Hz vibration and the
  ~100–105 Hz x/z peak. The backward-sample count also drifted across
  session 3 for the same move.
- **Unexplained:** the cause of the second lever drop on 2026-10-01.

**Housekeeping:** the bench servo is still ID 30. Rename it back to 11 when
bench work on it is done.

```bash
.venv/bin/python experiments/plan-b-bench/gain_bench.py --rehearse stiffness 30 --goal 2048 --rest 3072
MUJOCO_GL=cgl .venv/bin/python experiments/plan-b-bench/plan_b_rig.py   # Mac; egl on Linux
MUJOCO_GL=cgl .venv/bin/python experiments/plan-b-bench/plan_b_rig_v3.py
```

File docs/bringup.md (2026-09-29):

# Bring-up: bare board to first arm

This is the procedure that takes a General Driver board, a bag of STS3215s and an
assembled robot to a first armed run. The references it uses:

- electrical detail: [wiring.md](wiring.md)
- IDs, registers and calibration storage: [servo-map.md](servo-map.md)
- the CLI and firmware internals: [firmware/README.md](../firmware/README.md)
- the link: [control-channel.md](control-channel.md)

The firmware carries the robot's 17-servo bus (the proposed ID map,
[servo-map.md §2.1](servo-map.md#21-the-robot-the-proposed-map)): `cal`,
`pose`, `home`, `ping` and the gain check cover all 17, and touch only the
servos the calibration marks fitted. The compiled policy drives the
prototype's 10 joints. On the robot, the IMU check scripts in `tools/` still
hard-code the prototype's calibration, and the leg rows of the mechanical
envelope are the prototype's until they are probed on the robot (§3).

**Bench safety.** The rules are in [AGENTS.md](../AGENTS.md#bench-safety). Read
them before a session. Two of them are procedure, and every step below assumes them:

- **Opening the serial port reboots the board**, and the reboot eats the first command you send. After connecting, wait for the boot log, send an empty line, and check the prompt answers before any command that writes state (`id`, `cal …`, `middle`, `imu bias`, `wifi …`).
- **Any goal write is a motion command.** A goal-position write auto-enables torque on an STS3215. Never "verify" a calibration by driving the live robot at it. The firmware refuses `move` to a servo whose torque is off; `torque <id>` is the deliberate first half of every move.

## 0. Before you start

- **Laptop.**
  - ESP-IDF v5.4. `export.sh` will not run inside a virtualenv: `env -u VIRTUAL_ENV bash` first.
  - The repo's `.venv`, with pyserial.
  - On macOS, the CP210x driver.
- **Bench supply.**
  - A current-limited supply for first power. The 3S pack comes later, behind its protection board and fuse ([wiring.md](wiring.md#power-path)).
- **Stand and spotter.**
  - A test stand that holds the pelvis with the feet free.
  - A spotter for anything armed. The spotter says "go" before every arm.

## 1. Flash and first power

**Host gates first.**

```
make -C firmware/host test          # pure modules under ASan/UBSan
env -u VIRTUAL_ENV bash
. ~/esp/esp-idf/export.sh
idf.py -C firmware set-target esp32
idf.py -C firmware build
idf.py -C firmware -p /dev/cu.usbserial-XXXX flash monitor
```

**Flashing.**

- Flash through the USB-C port silkscreened **`USB`**. The one silkscreened `LIDAR` enumerates a serial port that never syncs.
- Flash with the pack disconnected. USB alone powers the ESP32's logic, because both USB-C ports are diode-OR'd into the 5 V rail. USB does not power the servo rail (`DC_IN`), so `scan` finds nothing until the XH inlet is powered. That is expected.

**The terminal.**

```
.venv/bin/python -m serial.tools.miniterm /dev/cu.usbserial-XXXX 115200
```

**What a good boot looks like.**

- The board boots in **bench mode with torque released**. Nothing moves until `run`, or an arm over the radio.
- The boot log reports:
  - `cal:` either `restored from NVS` or `DEFAULTS`;
  - `gains:` whether every servo's position-loop P/D read back as expected. With the pack off no servo answers, so this says `NOT verified`; `run` re-reads once the pack is on;
  - the IMU driver and whether its calibration came from NVS;
  - the joint count, the observation width, and the policy run (or `PLACEHOLDER`).
- `help` lists the commands.

**Checks after every flash.**

- `stat` must name the run you meant to flash.
- Run `imu reinit`, then `imu scan`. A flash can reset the board mid-read and leave SDA held, and boot then falls back to the stub IMU.
- `imu scan` must show 0x6B, the QMI8658C. The other on-board I²C parts are listed in [sensor-expansion.md §1](sensor-expansion.md#1-the-boards-connectors).

**Wi-Fi.** `wifi <ssid> <psk>` stores the credentials in NVS. Bench mode only.

**First power.**

1. Check the XH pigtail's polarity against the board's "− +" silkscreen. Pin 1 is V+.
2. Set the bench supply to **11.1 V, current limit ~0.5 A**, and power the bare board through the XH inlet. A short shows up as a limit trip instead of smoke.
3. Raise the limit to ~2 A for a single unloaded servo.

**The landing voltage.**

- **Land the robot by 10.5 V** (3.5 V/cell on 3S). battguard warns at 10.5 V and lands the robot at 9.9 V ([wiring.md](wiring.md#battery-protection)).
- The firmware's only voltage reading is a servo's register 62, at 0.1 V resolution (`scan`, `pos`, `volt`). The board's INA219 is not read.
- With one servo connected, compare its reading with the supply. The telemetry and the guard both use this number, so a constant offset is worth knowing now.

## 2. Servo IDs and gains

The robot's ID map is **proposed, awaiting sign-off** ([servo-map.md §2.1](servo-map.md#21-the-robot-the-proposed-map)).
Assign IDs only from the signed-off map. Every servo ships as ID 1, so set IDs
**one servo on the bus at a time**.

For each servo:

1. Board off. Connect this servo alone to a bus port. Board on.
2. `scan`: expect exactly one servo, at ID 1, with a sane voltage and `err 0x00`.
3. Check the part and its factory state:
   - `reg 1 3 2` = **777** (STS3215);
   - `reg 1 9 2` = 0 and `reg 1 11 2` = 4095 (angle limits);
   - `reg 1 33` = 0 (position mode);
   - `gains 1` = P 32, D 32, I 0 (registers 21/22/23).
4. `id 1 <new>`. Wait for `ok, verified after commit -- safe to power down`. `WROTE BUT DID NOT VERIFY` means rescan before trusting it.
5. Check it is alive:
   - `torque <new>`, then `move <new> 2048 0 200`, then a second target, then `release <new>`;
   - it should track to within a few ticks, with no fault flag;
   - a bare servo has nothing to hit, but only 0..4095 limits a servo that is not in the firmware's map.
6. Label the case with the ID and the joint name. Board off.

**Then chain.**

- Chain one port at a time. `scan` must enumerate exactly the expected IDs; `ping` with no argument checks the firmware's own list.
- If a servo is missing, or answers intermittently with `bad-reply` and 0.0 V, suspect a **duplicate ID** before the lead.

**Gains.**

- `gains` reads registers 21/22 on every servo the firmware drives and compares them with the expected table (`firmware/main/servo_gains.h`, [servo-map.md §4](servo-map.md#4-registers)). It must end `all N servos at their expected P/D`: `run` refuses otherwise (`REFUSED_GAINS` on the beacon).
- The six hip-roll, ankle-roll and knee servos get P ≈ 4× only after the stiffness bench test passes (issue #73). The expected table changes first, in a commit that names the measurement; then each servo is written.
- To write one servo: `release <id>`, then `gains <id> <P> <D>`. It refuses unless that servo's torque is off, unlocks the EEPROM (55 ← 0), writes 21/22, locks it again (55 ← 1), waits for the commit and reads back: wait for `verified after commit -- safe to power down`. It writes no goal.
- Power-cycle, then `gains` again: the values must have persisted.
- A replacement servo arrives at the factory 32/32. It fails the gate until it is written.

## 3. Calibrate: zeros, directions, IMU, clock

Do this on the assembled robot, on the stand.

### Zeros

There are two mechanisms, and they are not interchangeable (`cli.cpp`, "calibration"):

- `middle <id>` writes the **servo's** own offset. It is a coarse zero, stored in the servo's EEPROM.
- `cal …` writes the **firmware's** calibration in NVS: a fine zero trim, plus the direction sign.

1. Hold the robot at the standing pose, which is angle zero for every joint, with torque released.
2. `middle <id>` for each servo. It latches the current angle as 2048 and leaves that servo's torque **off**. This keeps every zero away from the 0/4095 encoder wrap. Never run it on a bare servo.
3. `cal zero` (all joints) or `cal zero <joint>` (a joint name or a servo ID), then `cal show`. With no joint named it also sets the **fitted** set: every servo that answers is fitted, and one that does not is marked `NOT FITTED`. Check that the fitted set is exactly the servos the robot carries (`cal fit <joint> 0|1` corrects it).
4. `cal save`. Reboot, and check the boot log says `cal: restored from NVS, N of 17 bus servos fitted`.

`run` and `home` refuse while the calibration is missing, or was measured under
another servo map; `run` also refuses while a joint the policy drives is not
fitted. A prototype calibrated before the 17-servo port boots with
`cal: migrated v2 -> v3`: its values carry over, IDs 1–10 fitted.

### Directions

`dir` cannot be read from the encoder. For each joint, alone:

1. `torque <id>`.
2. `move <id> <zero ± ~228 ticks> 0 200` (about 20°, at 200 steps/s).
3. Watch which way it goes, and compare with the sim's prediction for +20° on that joint ([servo-map.md §3.2](servo-map.md#32-direction-signs)).
4. `cal dir <joint> <1|-1>` (joint name or servo ID), then `release <id>`.
5. `cal save` at the end.

Never infer a sign from a compound motion.

### Envelope and play

- **Envelope.** Probe each joint's travel.
  - Set the goal to the present position before enabling torque.
  - Move one servo at a time, in small steps, watching the load in `pos`.
  - Record the result in `firmware/main/mech_envelope.h` and servo-map.md §3.3, in one commit.
- **Play.** Measure the play of every roll joint by tilt hysteresis. **≤ 3° is required; ≤ 1° is the target.**
  - Re-zero after any horn or mechanical work.

### IMU, in the standing pose

The QMI8658C is on the board, so the mount is a property of how the board is
screwed into the pelvis. Measure it on the robot; do not reuse another mounting.

1. `imu`: `who_am_i 0x05` and `levelled yes`.
2. **Mount.**
   - Run `imu raw` while tilting the robot by hand to identify the chip's axes.
   - Then set `imu mount <w> <x> <y> <z>` (sensor → body; saved to NVS).
   - Gravity cannot tell a mount from the same mount turned 180° about the vertical. So lean the robot forward deliberately: `imu` must show `projgrav.x` negative and `up.x` positive.
3. **Bias.** This comes after the mount. The CLI warns if the mount is still identity.
   - Hold the robot **still, in the pose it will run in**, and run `imu bias`.
   - Bias moves with orientation and temperature, so a bias taken on the desk does not transfer.
   - If `spread` is flagged, the robot moved: redo it.
   - The reported yaw drift after 30 s is the number that matters.
4. **Gyro scale.**
   - With one stance foot clamped, run `tools/imu_scale_check.py --leg L` (or `R`). It compares the gyro integral against the accelerometer's tilt change through a stance-ankle move.
   - Set the per-axis result with `imu gscale <x> <y> <z>` (sensor frame, saved to NVS).
5. **Sign and frame.**
   - `tools/gyro_sign_check.py --joint ankle --amp 6`, `tools/imu_axes_check.py`, `tools/imu_drift_check.py`.
   - Pass: the gyro integral within 0.5° and `up` within 0.02 of the sim, on the same ankle, hip and knee leans.

These scripts **command poses** (`home`, `pose`), so the robot moves. They also
hard-code the prototype's calibration table and `/dev/ttyUSB0`; porting them is part
of the open port.

### Clock and link

1. `wifi` until `CONNECTED`.
2. `ntp`: expect `synced`, with a server from DHCP and a step in the low milliseconds.
   - `UNSYNCED` after a minute means the router does not hand out DHCP option 42, and pool.ntp.org is unreachable from the robot's network.
   - Until the clock syncs, every telemetry `t_us` is 0.
3. `.venv/bin/python link/verify_udp.py --host <robot-ip>` sends disabled stand frames and listens for the 10 Hz beacon. It checks both directions with **no motion**.
4. `bimo_gui --host <robot-ip>`: the session JSONL in `hw_sessions/` must carry `robot_utc` on every beacon (not `null`).

## 4. Torque drills

Start on the stand, then move to the floor with the spotter.

**Check torque before anything else.** Servos have been found with torque dropped
overnight, refusing goal writes with no fault flag and no reboot. `reg <id> 40`
reads 1 when torque is on.

1. **Engage and release.**
   - `torque [id]` and `release [id]`; with no ID they broadcast.
   - Confirm that `move` refuses on a released servo.
2. **Reset to the stand.** `home` does the following:
   1. Enables torque.
   2. Slews every joint to its calibrated zero on a minimum-jerk profile (2.5–8 s).
   3. Takes up hip-roll play with a 5° out-and-back on each hip.
   4. Reads every joint back, which must be within 12 ticks (~1°).
   5. **Releases torque**. Gear friction holds the stand.

   About the verdict:
   - `home` refuses without calibration, or with the pack guard latched.
   - RESET SERVOS on the link runs the same sequence. Its `DISARMED_HOME` verdict means the joints were read back at their zeros, not merely written.
3. **Passive stand.** Stand the robot up, release torque, and watch.
   - If it holds, joint friction is enough, and idle torque-off is feasible.
   - If it collapses or drifts more than 10 cm, it is not.
   - This is the unpowered backdrive friction measurement that no bench tool has made ([servo-map.md §5](servo-map.md#5-measured-sts3215-behaviour)).
4. **Arm on the stand and read the loop timing.**
   - Arm with `run`, or over the link.
   - Read `stat`: late ticks at 0 %, the worst tick, and the per-phase microseconds. The bus time for the full servo set is measured here.
5. **The watchdog.** With a commander connected and the robot armed on the stand:
   - Kill the commander. The robot should go to `STAND` after 250 ms, then to `RELAX` (torque off) at 5 s.
   - E-stop latches, and clears only on a frame with `ENABLE` off.
6. **Disarm does not lower the robot.** A disarm releases torque, friction holds the joints, and a rigid body tips. End every probe with RESET SERVOS **while still armed**.
7. **Guards.**
   - `FALLEN`: `up_z` below 0.4 for 200 ms releases torque and benches the loop. Re-arming takes a fresh arm.
   - The pack guard: `batt` shows its level. `batt reset` is for after a pack swap only.
   - After any fall or guard trip, RESET SERVOS.

## 5. The offline flash gate

No policy is flashed until it passes all of the following, offline:

1. **Referee.** On the lag referee: `stand_10s` 8/8 and `stand_off` ≥ 6/8.
2. **Tick 1 at home.**
   - Feed the robot's home observation to the exported student (`.silw` through `sim/sil/harness.py` `silw_forward`).
   - The first action must be **≤ 0.05 on every joint**.
   - The zero pose is the stop/rest pose. A policy that asks for motion at home walks the robot off its own stance.
3. **Twin rest.**
   - Run the SIL twin, `sim/sil_twin.py` (nominal plant) with `--act-delay-ticks 4` for the servo's dead time.
   - Over the last 3 s of a 6 s stand, every joint must rest **within 2° of home** and the torso **within 1°**.
4. **Build.** Then run:
   - `make -C firmware/host deploy-headers RUN=<run>`;
   - the host tests;
   - SIL ([sim/sil/README.md](../sim/sil/README.md));
   - `idf.py -C firmware build`.
5. **Check.** Flash, then check that `stat` names the run, and run `imu reinit` and `imu scan`.

A policy that scores well in the referee can still fail tick 1 or twin rest.
Referee scores are gates, not proof.

## 6. Staged hardware gates

- Every stage has a sim gate and a hardware gate, and nothing advances on a feeling.
- Record every arm: camera, and the beacon CSV (`tools/record_attempt.sh`).
- Change one variable per run.
- Before blaming a sensor, run the same input through the twin.

**Before any policy.**

1. Weigh every part.
2. Confirm roll-joint play is within bounds (§3).
3. Put the measured stiffness, play and masses into the plant.
4. Re-run the gates: `sim/gate_no3250.py walk | sweep | arms | getup`.
5. Then run the floor sequence **over the tether, one motion per go**: stand → crouch → shift → one-foot → step in place → six steps.
   - The motions are the `sim/static_gait.py` keyframes, streamed through the firmware's `pose` path.
   - Record each step as a margin, clearance and slip number, against the sim's.
6. Then the scripted get-up.
7. Measure the bus current here ([wiring.md](wiring.md#current-the-open-constraint)).

**Policy stages**, once a policy is trained on the measured plant:

| stage | sim gate (lag referee) | hardware gate |
|---|---|---|
| 1. Stand: rest is home | §5 | 5 arms × 30 s on the pad at full gyro gain: no guard, hip-pitch swing < 0.05 rad, hip-roll and yaw drift < 3°, torso within 3°. Then 3 × 30 s on bare wood. Then 5 pushes of ±2 cm at the pelvis, each recovered without a step |
| 2. Posture | `squat_reps` ≥ 6/8, `weight_shift` ≥ 6/8 | 3 crouch-and-return cycles from the slider, 3 s each way, no guard, torso pitch within 5°. A 60 s hold at half crouch, swing < 0.05 rad |
| 3. Step in place | `march_in_place` ≥ 6/8, feet clear 2 cm | 10 s march with both feet visibly clear: 3/3 on the pad, 2/3 on wood. Stops to a quiet stand within 1 s |
| 4. Walk and turn | `line_1m`, `backward_1m` ≥ 6/8; `turn_180`, `reversal` ≥ 5/8 | vx 0.15 for 1 m, 3/3, lateral drift < 20 cm, stops within 1 s. 90° in place, 3/3, heading error < 20°. Forward → backward, 2/3. The line and the turn on the pad, and one of them on wood |
| 5. Joystick | — | Caps vx ≤ 0.2 and wz ≤ 0.5. 5 min of free driving on the pad with at most one assisted catch, twice; then 5 min on wood |

The recovery gesture throughout is RESET SERVOS while armed. Releasing torque does
not lower the robot.

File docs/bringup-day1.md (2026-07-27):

# Bring-up day 1 — board power-on + servo IDs

*2026-07-26, the day the Servo Driver with ESP32 arrived. Companion to
[wiring.md](wiring.md) §Bring-up checklist (the short form) and
[firmware-design.md](firmware-design.md) §7 (what happens after this).*

> ## ⚑ SUPERSEDED, 2026-07-26 — we flashed. Use the USB CLI.
>
> This page originally said to do all of bring-up on the stock vendor
> firmware and flash afterwards. **That advice was wrong and is withdrawn.**
> It assumed the vendor web UI was a usable tool; it is not — it byte-swaps
> every 16-bit value it exchanges with an ST3215 and corrupts angle limits
> (measured, boxed below). It also cannot be driven without rejoining the
> board's WiFi after every power cycle.
>
> Our firmware is flashed and **verified on hardware**. Bring-up is now one
> USB cable and no WiFi:
>
> ```
> .venv/bin/python -m serial.tools.miniterm /dev/cu.usbserial-0001 115200
> ```
>
> ```
> scan                     ping IDs 0-253, report position/voltage/faults
> id <old> <new>           assign an ID (EEPROM, one servo on the bus)
> pos <id>                 position, speed, load, voltage, temp, faults
> move <id> <ticks> [ms]   2048 == middle, 4096 ticks per revolution
> release [id] | torque [id]
> middle <id>              latch the current angle as 2048
> volt | stat | run | bench
> ```
>
> The stock image is backed up at `firmware/vendor-backup/` if it is ever
> needed again — see the README there for the restore command.
>
> Sections 2–3 below still describe the vendor UI. Kept for the measurements
> and the root-cause analysis, not as instructions.

Vendor facts confirmed 2026-07-26 from Waveshare's docs (sources at bottom):

| | |
| --- | --- |
| Power in | **6–12.6 V DC**, 5.5 × 2.1 mm barrel jack, **5 A max through the board** |
| WiFi AP | SSID `ESP32_DEV`, password `12345678` |
| Web UI | <http://192.168.4.1> — **use Chrome** |
| USB serial | 115200 baud |
| Power-on servo scan | IDs **0–20** (our map tops out at 10 — no `MAX_ID` edit needed) |

---

## 0. Before power — verify the part (10 min, unblocks a print)

- [ ] Confirm the silkscreen actually reads **"Servo Driver with ESP32"**,
  
      65 × 30 mm. If it says **"Bus Servo Driver HAT (A)"** (65 × 57 mm), it
      is the wrong board — 9–25 V in, Pi form factor, won't fit the tower.
      See [hardware-order.md](hardware-order.md) caveat 2.
- [x] **Mounting holes — VERIFIED 2026-07-27.** The board test-fits the
      printed tower with all four screws landing, which checks both spans and
      the hole diameter together. `BOARD_HOLES = (58.0, 23.0)`, Ø2.75, stands
      as published. No calipers needed after all.
- [ ] Confirm power in is the **DC-044 5.5 × 2.1 barrel jack (CN1) and
  
      nothing else** — the schematic shows no screw terminal, so the XT30
      pigtail needs a **barrel plug, centre positive**. The board's other
      3-pin header (H1, XH1.25) is 5 V / GND / **LED-OUT**, an output for
      addressable LEDs; don't feed the pack into it.
- [ ] Caliper the servo bus connector pitch and confirm the pin order on the
  
      board matches the servo leads: **1 GND (black) · 2 V+ (red) · 3 DATA**.

## 1. First power, bare board (no servos)

Bench supply strongly preferred over the LiPo for first light: set
**11.1 V, current limit ~0.5 A**. A short shows up as a limit trip instead
of smoke.

- [ ] Power up. OLED lights, shows something (voltage / status).
- [ ] Current draw is sane (tens of mA, not amps).
- [ ] Laptop → WiFi → `ESP32_DEV` / `12345678`.
- [ ] Chrome → <http://192.168.4.1>. UI loads.
- [ ] Read bus voltage on the OLED and in the UI; sanity-check it against
  
      what the bench supply says. That reading is what the 10 Hz telemetry
      will report later, so a constant offset is worth knowing now.

Power down before touching the servo bus.

## 2. Servo IDs, one servo at a time

**Every servo ships as ID 1.** Two servos with the same ID on the bus do not
enumerate — you get silence, not an error. So: exactly one servo connected
at a time, and **power off the board between swaps** (don't hot-plug the bus).

Raise the bench limit to **~2 A** for this step (one servo, unloaded, idles
~0.18 A and moves well under 1 A).

Target map — **unchanged, keep assigning to this**:

| ID  | Joint | | ID  | Joint |
| --- | --- | --- | --- | --- |
| 1 | L hip roll  | | 5 | R hip roll  |
| 2 | L hip pitch | | 6 | R hip pitch |
| 3 | L knee | | 7 | R knee |
| 4 | L ankle | | 8 | R ankle |
| 9 | L hip yaw | | 10  | R hip yaw |

(9/10 are the v3yaw plant's hip yaws — the current plant of record is
10-DOF. If only 8 servos are in hand, assign 1–8 and leave 9/10 for the
yaw pair.)

> **Correction 2026-07-26.** [wiring.md](wiring.md) claimed this map means
> "the policy's action vector maps to IDs 1–8 with no permutation table."
> That was true on the retired 8-DOF plant and is **false on the deployed
> 10-DOF v3yaw plant**: the sim's action order is
> `[L_hip_yaw, L_hip_roll, L_hip_pitch, L_knee, L_ankle, R_hip_yaw, …]`, so
> action 0 is the servo we call bus ID **9**. **Nothing about the physical
> assignment changes** — the firmware carries a generated, tested permutation
> (`obs::kServoId = {9,1,2,3,4,10,5,6,7,8}`). Keep labelling to the table
> above. Renumbering to make the mapping an identity was considered and
> rejected: it would invalidate wiring.md, assembly.md and the connector
> guide to save a lookup table that is generated from the sim anyway.

Assign **from the top down (10 → 1)**, so you never transiently create a
second ID 1 while a servo already at ID 1 is on the bench nearby.

### Use `tools/servo_tool.py`, not the web UI

**The vendor web UI cannot do this job** — see the box below for why. Instead,
put the board into its USB↔bus bridge mode once per power cycle and drive the
servos directly:

```
# on the board's WiFi (ESP32_DEV / 12345678), once per power-up:
.venv/bin/python tools/servo_tool.py bridge on     # OLED reads SERIAL_FORWARDING

# then everything over USB — exact values, no clicking:
.venv/bin/python tools/servo_tool.py scan
.venv/bin/python tools/servo_tool.py setid 1 9
.venv/bin/python tools/servo_tool.py move 9 2048
```

For each servo:

- [ ] Board off. Connect this servo alone to bus port A. Board on.
- [ ] `servo_tool.py scan` → exactly one servo, at ID **1** (the factory ID).
- [ ] `servo_tool.py info 1` → if `angle limits` is not `0 .. 4095`, run
      `servo_tool.py fixrange 1` (the vendor UI clamps ST3215s to SC range).
- [ ] `servo_tool.py setid 1 <target>` — refuses if the target ID is already
      live, and verifies the servo answers on the new ID before reporting
      success. Written to EEPROM, survives power-off.
- [ ] `servo_tool.py move <target> 2048` then `move <target> 1400` — the DOA
      test, at the correct 0–4095 full scale.
- [ ] **Label the case** with the ID *and* the joint name, in marker, on the
      flat face you'll still be able to read after assembly.
- [ ] Board off. Next servo.

> ### 🔴 The vendor firmware talks to ST3215s with the bytes reversed
>
> **Measured on the bench 2026-07-26, not inferred.** The board runs the
> **SC-series** build. `SCSCL` sets `End = 1` (big-endian); `SMS_STS` sets
> `End = 0` (little-endian). The ST3215 is ST series — so **every 16-bit
> value the board exchanges with these servos has its two bytes swapped.**
>
> Confirmed two independent ways on servo ID 9:
>
> | | board (big-endian) | read correctly (little-endian) |
> |---|---|---|
> | present position | 772 (`03 04`) | **1027** (`04 03`) |
> | angle limits after "Set Servo Mode" | wrote 20, 1003 | **5120, 60163** |
>
> `20 = 0x0014` sent big-endian arrives as `0x1400` = 5120; `1003 = 0x03EB`
> arrives as `0xEB03` = 60163. Both predicted before reading, both exact.
>
> **What follows from this:**
>
> - ✅ **8-bit registers are safe through the web UI** — byte order cannot
>   corrupt a single byte. That means **ID** (reg 5), **mode** (33) and
>   **torque** (40). `http-setid` is therefore trustworthy, and it needs no
>   USB cable.
> - ❌ **Every 16-bit value is garbage** in both directions: position, speed,
>   and angle limits. Do not trust a position the UI reports, and do not use
>   its Position± / Middle / Set Servo Mode buttons on an ST3215.
> - ⚠️ **"Set Servo Mode" corrupts the angle limits.** Any servo that has met
>   that button is clamped by junk values until `fixrange` repairs it. Check
>   every servo with `info` before it goes into a leg.
>
> The servo itself is fine — none of this damages hardware, and ID 9 tracked
> 600 / 2048 / 3500 to within ±3 counts after repair.

> ### ⚠️ Secondary: the UI's other quirks (from its source)
>
> Read out of Waveshare's own
> [firmware source](https://github.com/waveshare/Servo-Driver-with-ESP32):
>
> 1. **It is built for the wrong servo family.** `STSCTRL.h:15` has
>    `SERVO_TYPE_SELECT = 2` — **SC series**, `ServoDigitalRange = 1023`. The
>    ST3215 is **ST series, range 4095**. The commented-out lines right below
>    are the ST settings the vendor didn't enable. So "Position+" commands
>    ~1003 counts on a servo that has 4095 — about a quarter of travel, which
>    is exactly the "doesn't do much" symptom.
> 2. **The ID field moves ±1 per click** (`servotoSet += 1`, wrapping at 250),
>    so reaching 9 means nine clicks with no overshoot — and one overshoot
>    costs 240 more clicks to wrap around.
> 3. **`setMode(id, 0)` in SC mode writes SC angle limits (20…1003) to
>    registers 9/11** — which the ST series uses for the *same* purpose. Any
>    ST3215 that has been through the UI's mode button is now clamped to ~24 %
>    of its travel. `servo_tool.py fixrange <id>` puts registers 9/11 back to
>    0…4095 and mode to 0. **Check every servo you touched with the UI.**
>
> The tool sidesteps all three by using the vendor firmware's own
> `SERIAL_FORWARDING` mode (`BOARD_DEV.h:157`), a byte-for-byte USB↔bus
> bridge, and speaking the real Feetech ST protocol from the laptop. Its
> packet encoder is checked against the worked examples in Feetech's protocol
> manual — the same golden vectors the firmware's C++ bus layer passes.
> **Nothing is flashed; the vendor firmware is untouched.**

Keep a tally here as you go — DOAs and surprises:

| ID  | Joint | Assigned | Moves | Notes |
| --- | --- | --- | ----- | ----- |
| 1 | L hip roll  | ✅ | ✅ | 2026-07-26, USB CLI. 200→3900 clean, ±3 ticks, 27 °C — factory ID, no reassignment needed, err 0x00. |
| 2 | L hip pitch | ✅ | ✅ | 2026-07-26, USB CLI. 200→3900 clean, ±3 ticks, 28 °C, err 0x00. |
| 3 | L knee | ✅ | ✅ | 2026-07-26, USB CLI. 200→3900 clean, ±3 ticks, 28 °C, err 0x00. |
| 4 | L ankle | ✅ | ✅ | 2026-07-26, USB CLI. 200→3900 clean, ±3 ticks, 27 °C, err 0x00. |
| 5 | R hip roll  | ✅ | ✅ | 2026-07-26, USB CLI. 200→3900 clean, ±3 ticks, 28 °C, err 0x00. |
| 6 | R hip pitch | ✅ | ✅ | 2026-07-26, USB CLI. 200→3900 clean, ±3 ticks, 29 °C, err 0x00. |
| 7 | R knee | ✅ | ✅ | 2026-07-26, USB CLI. 200→3900 clean, ±3 ticks, 26 °C, err 0x00. |
| 8 | R ankle | ✅ | ✅ | 2026-07-26, USB CLI. 200→3900 clean, ±3 ticks, 30 °C, err 0x00. |
| 9 | L hip yaw | ✅ | ✅ | 2026-07-26: set from factory ID 1 over WiFi. Angle limits were corrupted (5120..60163) by the UI's Set Servo Mode; `fixrange` restored 0..4095. Tracks 600/2048/3500 to ±3 counts, 12.0 V. |
| 10  | R hip yaw | ✅ | ✅ | 2026-07-26. First web-UI attempt did not stick (came back as ID 1); reassigned over the USB CLI and **confirmed across a servo power cycle**. 200→3900 clean, ±3 ticks. |

## 3b. Full-chain result, 2026-07-26 — 10 of 10 ✅

All ten servos on one bus, via the flashed firmware's `ping` (no argument),
which checks exactly the IDs the policy expects, **in action order**:

```
L_hip_yaw    id  9  ok      R_hip_yaw    id 10  ok
L_hip_roll   id  1  ok      R_hip_roll   id  5  ok
L_hip_pitch  id  2  ok      R_hip_pitch  id  6  ok
L_knee       id  3  ok      R_knee       id  7  ok
L_ankle      id  4  ok      R_ankle      id  8  ok
10 of 10 present            bus 12.0 V
```

That ordering is the first hardware confirmation of
`obs::kServoId = {9,1,2,3,4,10,5,6,7,8}` — the permutation wiring.md wrongly
called an identity. Bus voltage fell only 12.0 → 11.9 V worst-case with all
ten powered, consistent with the ~0.85 A mean in
[wiring.md § Power path](wiring.md).

### The duplicate-ID signature, worth recognising

An earlier run of this same test read **8 of 10**, with ID 9 missing and ID 1
answering intermittently (3/10 pings), returning `bad-reply` and a nonsense
`0.0 V`. That was **not** a loose connector — it was **two servos both
answering as ID 1**, because servo 9's assignment (made through the vendor
web UI) had silently reverted.

Mechanism, from the vendor library: **SCSCL locks EEPROM at register 48, the
ST series at 55.** The SC-build firmware's "unlock" therefore never unlocked
anything on an ST3215, so ID writes through it did not persist — and it left
a stray value in reg 48, the torque limit. Our firmware uses 55, and all ten
assignments made through it have held.

**If a chained servo is intermittent with garbage reads, suspect a duplicate
ID before suspecting the wiring.**

## 3. Chain test, one leg at a time

- [ ] Board off. Chain IDs 1→2→3→4 off port A (each ST3215 has two
  
      internally-paralleled ports, so it's case-to-case hops).
- [ ] Board on, limit ~3 A. Confirm the scan enumerates **exactly 4** servos
  
      at the expected IDs.
- [ ] Repeat for 5→6→7→8 on port B. Then both legs together: **8 enumerate.**
- [ ] Then add 9/10 if present: **10 enumerate.**

Missing servo ⇒ suspect the lead or a duplicate ID, in that order.
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

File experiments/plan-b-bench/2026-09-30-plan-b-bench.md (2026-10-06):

# Plan B bench, session 1 (2026-09-30): the bench servo, unloaded

Issue #73, [DESIGN.md §13](../../DESIGN.md) step 0. This session read the
bench servo and ran every rung of the P ladder on a **bare horn**: no lever, no
masses, no inertia. It could therefore rule out a servo that buzzes unloaded,
but it could not measure stiffness. The stiffness table and the stance number
(steps 0 and 1 as written) are still to be taken.

Tool: `gain_bench.py` in this folder (then `tools/gain_bench.py`), at main eef3abe. The session was run by the Claude
session on Mira as `claw`, on Tom's instructions. The raw data (JSON per step
and `session.log`) is in [`2026-09-30/raw/`](2026-09-30/raw/): `gain_bench/` (the
scan and register reads) and `gain_bench_bare/` (the pass). The table below is
[`2026-09-30/bare_ladder_summary.json`](2026-09-30/bare_ladder_summary.json),
written from the raw files by `summarise_raw.py`. How to repeat it on your own
bench: [REPRODUCE.md](REPRODUCE.md).

**Two attempts stopped before the pass** (both in `gain_bench_bare/session.log`):
- **11:24:** the first gains write was judged on the firmware's progress line,
  not its verdict. That was fixed in 1e231d0 at 11:27.
- **11:28:** the P 64 write reported `FAILED (write-failed)` although it may
  have landed (#101, below). `hold.112838.json` holds that one rung.

The pass in the table ran at **11:32**.

## The rig

- **Board**: the prototype's old controller (ESP32-D0WD-V3 rev 3.1) on Mira's
  tether. It was flashed with main 98c9ced, because the build it had predated
  `gains` (#94). The flash kept NVS, and with it the prototype's
  calibration, in which ID 11 is `NOT FITTED`.
- **Servo**: one STS3215 (Model_Number 777, servo firmware 3.10), alone on
  the bus, nothing on the horn.
  - It arrived as ID 1 and was re-IDed to **11**. On the robot it will be
    `R_ankle_roll`, one of the six Plan B servos.
  - ID 11 is on the bus map, so `move` is clamped to `R_ankle_roll`'s
    envelope, which on this board (zero 2048, dir +1, ±25°) is **1764..2332**.
  - The horn was found at 4094, on the encoder wrap, and was moved to 2050
    before the pass.
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

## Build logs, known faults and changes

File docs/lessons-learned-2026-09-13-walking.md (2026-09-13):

# Lessons learned, 2026-09-13: this hardware does not support walking, and why it took two months to say so

Written the evening the robot fell off the table and broke its hip roll joints, at Tom's request: "confront the fact that there is a design flaw in this hardware: it doesn't support walking ... be sure to include why it took us so long to catch this defect." What follows is what the record supports, what I believe, and where I was part of the delay.

## 1. What the hardware can and cannot do

Measured today on the bench with open-loop joint commands, no policy, and cross-checked in the MuJoCo plant with the deploy servo model (all numbers in `hw_sessions/2026-09-13/notes.md`):

- **It can stand, squat and return.** Reference squats to hip −65 / knee −95 / ankle −40 with every joint within 0.5° of command, six for six. The v41rsi_b policy squats on it three for three.
- **It cannot shift its weight onto one foot from rest.** There is no ankle roll joint. With both feet flat, a planted foot pins the pelvis level, so rolling a hip cannot move the centre of mass; the roll servos slide the feet on the pad (torso centroid unmoved on camera at a 12° lean, servo loads 88–168) or stall (stance hip 1.2° short at load 120). Shortening a leg pivots the body about the stance foot's inner edge, which carries the centre of mass *toward* the lifted side: every "lift" tilted the body onto the lifted foot (8.0° for a 1.1 cm shortening, which is atan(1.1 / 8 cm hip width)). The sim sweep finds no lean angle between "falls back onto the other foot" (≤14°) and "tips over sideways" (≥16°).
- **A single step from rest is a prop, not a stride** (Tom's verdict, sim agrees: the sole clears by ~3 mm for ~200 ms while the body tips onto it).
- **The only regime in which this kinematics can unload a foot is dynamic:** a lateral rock on the foot edges. The sim reaches it (a 10–14° hip-roll rock at 0.6–0.8 s sways the torso 13–35° and lifts the feet 1–3 cm) but the band is narrow and bounded by resonance falls, and the one hardware attempt at it put the robot off the table.

So the precise statement is: **the kinematics (5 DOF per leg, no ankle roll, rigid flat 5 cm feet on an 8 cm hip base) permits walking only as a dynamic edge-rocking gait, and the implementation — servo speed under load, 1–2° of play in the yaw/roll chains, sole friction on the pad — leaves no usable margin inside that regime.** In the simulator the same kinematics walks (20 cm steps, metronomic cadence, 2026-08-18), because the simulator's feet rock on their edges without sliding, its joints have no play beyond the modelled backlash, and its servo reaches its measured no-load speed. On the robot the same commands produce the shuffle we have been looking at since 2026-09-08.

## 2. The signals we had, and what we said about each

| date | signal | what we concluded at the time |
|---|---|---|
| 2026-07 | design: 5 DOF/leg, no ankle roll (docs/servo-map.md); hip-yaw redesign work on play | a yaw/roll play problem to fix mechanically, not a walking-capability question |
| 2026-08-02 | plant knee axis had sim and robot bending opposite ways | fixed in sim; no capability review |
| 2026-08-18 | v21sched walks in sim: 100% alternation, 20 cm steps | "cadence is metronomic"; the sim was taken as proof the body can walk |
| 2026-08-30/31 | ground attempts: falls (issue #29) | fall-latch and arming logic; "Stage 0 CoM + friction gap" noted, not pursued |
| 2026-09-02 | zero-command stand: ~1 Hz **roll** rocking and sideways falls on hardware, still in sim; play measured by tilt hysteresis (L hip roll 2–3° step, R knee 3.5°); free-travel play in the twin did **not** reproduce it | attributed to play and a coupling chain; "right ankle closed" after a hands-on lurch fix |
| 2026-09-03 | horn screws loose, re-zeroed; leg_rom lifts one foot **with the other foot clamped** (Tom's instruction) | the clamp was a safety measure; nobody wrote down that it was also the only way a foot came up |
| 2026-09-07 | a held forward pulse steps 1.5× the twin on hardware and falls 2/3; "Stage 0 CoM + friction gap" again | tethered obs dump planned to find a sensing gap |
| 2026-09-08 | the twin's forward step is a **1 cm shuffle**; Tom: "foot lift + feet apart" | treated as a reward problem: swing-height and foot-cross terms (v36swing) |
| 2026-09-11 | v37knee_b "crouch" on hardware = hip-yaw pinch, no descent; twin reproduces | policy behaviour; probe contamination found the same day |
| 2026-09-13 morning | v41rsi_b squats on the robot; toe-in and feet-together are hardware-only (twin shows neither) | a sim-to-real gap on the yaw/roll channels; obs-dump planned |
| 2026-09-13 afternoon | open-loop balance, step, rock: the measurements in §1 | **the capability question, asked directly for the first time, answered in three hours** |

The pattern in the right-hand column is the finding: every hardware failure received a local, plausible, single cause — play, a loose horn, a coupling chain, IMU bias, a reward term, a calibration, a probe bug — and each of those was real. None of them was checked against the simplest question: *can this body take its weight on one foot at all?* That question needs no policy, no referee and no GPU, and it took one afternoon with a serial cable.

## 3. Why it took so long

1. **The simulator walked, and we let that stand in for the body.** Since 2026-08-18 the plant has walked with metronomic cadence, so "the kinematics is fine" was never re-examined. The sim was calibrated where we looked (geometry from CAD and the as-built check, servo no-load speed measured on a free knee, backlash, latency, dead time) and not where it mattered for this question: foot-edge rocking, sole friction on the actual pad, and play downstream of the encoders. The twin inherits the same plant, so "the twin reproduces it" was reassurance about the firmware loop, not about the body.
2. **We went to reinforcement learning before we went to the bench.** The whole pipeline — trainer, referee, distillation, twin, deploy — was built and iterated for seven weeks before anyone commanded a joint by hand and asked what the body does. When the policies shuffled, the natural move inside that pipeline was another reward term.
3. **The roadmap's gates were standing and crouching first.** Sensible for safety, but it meant the walking gate — the one that would have exposed this — was always the next hop. Every stage we passed (stand still, zero at home, squat) is a static skill, and this body is fine at static skills.
4. **Each failure had a true local explanation.** Loose horns were loose. Play was 1–2°. The probes were contaminated. The reward did lack a swing term. Fixing real things felt like progress and each fix was measured to help a little, which is exactly what a wrong model of the problem produces.
5. **The clamp hid it.** On 2026-09-03 single-foot lifts were done with the other foot clamped to the table on Tom's instruction. That was the right call for safety and it worked perfectly, which is why it never occurred to us that without the clamp the same lift is impossible.
6. **My own part.** I stated motion from camera frames twice ("lowered, then back to parallel" on 09-11; "the right sole is off the table" today) and was corrected both times by Tom's eyes. I ran probes with a contaminated setting for three weeks. I attributed the shuffle to the reward with confidence. And this afternoon I ran a dynamic maneuver on the table straight after building it, when the sim had shown the same family falling at neighbouring parameters. Confident local explanations are how a two-month delay is built.

## 4. What this means for the project

- **Everything static stands.** Standing, zeroing, the squat, the deploy pipeline, the referee, the twin as a firmware-loop check, reference-state initialization as a training technique: all of that is real and measured, and today's sim-versus-bench agreement on the negatives is evidence the plant is trustworthy for the questions it was calibrated for.
- **Walking on this body needs a hardware change, not a reward term.** The candidates, in order of how directly they address the mechanism: an ankle roll joint per leg (6 DOF/leg, the standard answer to lateral weight shift); failing that, wider feet with compliant, high-friction soles so the edge-rocking regime has margin, plus taking the yaw/roll play out of the chains; and faster or stronger actuation only helps once one of those is done. A shuffle gait (feet sliding, never lifting) is the other honest option and would need its own sim contact model.
- **Tonight's queue stays** (v42deep, v42deepfast: squat depth and toe-in on a body that squats), because those are static skills the body has.

## 5. Process changes, effective now

1. **Bench before policy.** Any new capability claim about the body (a lift, a step, a turn, a push recovery) is first tried open-loop over the tether with joint readbacks and cameras, and the result is written down, before any training run targets it. `tools/squat_bench.py` is the start of that kit.
2. **Calibrate the sim where the question lives.** Before trusting the plant on a contact-dominated question, measure the thing: sole friction on the pad, what the feet do at a 10° lean, joint speed under body load (the "200 ms" pose that took 600 ms is still unexplained), play downstream of the encoders. Put the measured numbers in the plant or say the plant is not calibrated there.
3. **Dynamic tests need a per-attempt go, on the floor, with a stated sim margin.** A tilt-abort that reads between poses cannot catch a dynamic fall. The robot does not do dynamic experiments on a table again.
4. **Frames are not measurements.** Motion claims come from encoders, IMU, tracked features across frames, or Tom's eyes, in that order of preference for each quantity, and "cannot tell from the camera" is an acceptable answer.
5. **One question per failure:** before a local fix, ask whether the same symptom would appear if the body simply could not do the thing. Today that question was cheaper than any fix we made in the preceding month.

## 6. Open items carried out of today

- Repair of the hip roll joints (Tom); re-zero (`cal zero` / `cal save`) if horns moved; the next hardware session starts with a stand test.
- The servo-speed question: the firmware smooth streamer versus the servo under load.
- The obs-dump test that would split policy-commanded toe-in / adduction from servo sag.
- A decision on the hardware direction in §4 before more walking-oriented training is queued.

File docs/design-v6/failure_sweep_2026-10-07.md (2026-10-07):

# Failure sweep of the kinematic walk, 2026-10-06/07

> Dated record: accurate as of its date; the current design is [DESIGN.md](../../DESIGN.md).

Tom (2026-10-06): run simulations overnight looking for failure modes, and make
sure that one foot actually lifts off the ground. `sim/failure_sweep.py` walks
`static_gait`'s kinematic gait (8 steps, open loop) on the committed plant
(`sim/bimo_biped_v6ar.xml`, main @ 146f714 / 39a12c4: the 6810-2RS hip, the
roll bay 5 mm lower, the folded arm rest pose, STS3250s at the hip rolls). The
conditions are sampled uniformly and every walk is classified. These are
open-loop results: they show where the body and the kinematic gait break, not
what a trained policy can recover.

| sweep | where | walks | space |
|---|---|---|---|
| wide | laptop, 20:50–03:03 | 382,200 | `--space wide`: edges (play to 6°, backlash to 3°, mu 0.3–1.2, servos down to 65 %, tilt ±3°, any lag, stunt gaits) |
| realistic | laptop, 03:16–06:45 | 52,224 | `--space realistic`: the expected envelope (play ≤ 3°, backlash ≤ 1.5°, mu 0.5–1.0, servos 85–100 %, the bench's stiffness band, tilt ±1.5°, normal walking) |
| wide | Mira CPU, 22:00–06:45 | 253,888 | `--space wide`, independent seeds: every category rate within 0.3 points of the laptop's, every marginal below within 0.6 |

Classes: **fell**; **no_lift** (a completed step whose swing sole peaked under
15 mm); short_air (< 0.3 s airborne); slip (stance foot > 10 mm); low_margin;
torque / speed saturation; heading drift.

## Rates

| | wide | realistic |
|---|---|---|
| clean | 10.4 % | 30.8 % |
| fell | 70.6 % | 24.6 % |
| no_lift | 44.5 % | 53.4 % |
| short_air | 28.7 % | 22.2 % |
| slip | 29.7 % | 1.2 % |
| torque / speed saturation | 1.6 / 1.2 % | 0.0 / 0.0 % |

## What moves them (rate in the lowest / highest third of each range)

| parameter | realistic: fell | realistic: no_lift | wide: fell | wide: no_lift |
|---|---|---|---|---|
| roll play | **2.4 → 50.6 %** (0–1° → 2–3°) | 49.6 → 55.4 % | 45.3 → 92.3 % | 52.3 → 33.2 % |
| backlash | 16.2 → 33.1 % | 49.1 → 57.4 % | 57.8 → 83.3 % | 45.3 → 43.4 % |
| actuation lag pole | 1.6 → 36.2 % (1 → 3 Hz) | **93.5 → 33.0 %** | 67.3 → 74.0 % | 51.2 → 37.7 % |
| commanded lift | 21.0 → 27.1 % | **83.3 → 29.5 %** (3.0–3.7 → 4.3–5.0 cm) | 66.6 → 74.5 % | 75.6 → 16.5 % |
| swing time | 34.0 → 13.8 % (short → long) | 60.7 → 44.8 % | 78.1 → 62.8 % | 49.2 → 40.0 % |
| friction (mu) | 17.5 → 31.1 % | 51.1 → 55.0 % | 59.4 → 79.2 % | 47.0 → 42.6 % |
| fore-aft tilt | 30.7 → 21.7 % (backward → forward) | 58.2 → 50.9 % | 84.1 → 63.8 % | 43.4 → 46.4 % |
| mass | 20.4 → 28.7 % | 50.2 → 56.5 % | 64.2 → 76.8 % | 45.6 → 43.4 % |
| servo strength, tuned-STS3215 and STS3250 stiffness | flat (± 2–4 points) | flat | flat | flat |

Single-parameter marginals of a uniform sample: interactions are not separated.

## Findings

1. **Roll-joint play decides whether the walk falls.** Inside the ≤ 3°
   requirement, 0–1° of play falls 2.4 % of the time and 2–3° falls 51 %.
   The ≤ 1° target is a requirement for the open-loop walk, not a nicety;
   measure the printed hips' play first (#79).
2. **The swing foot loses most of a small commanded lift.** A 3.0–3.7 cm
   command leaves the sole under 15 mm in 83 % of walks; 4.3–5.0 cm in 30 %.
   The reference gait should command about 5 cm to get a real lift.
3. **Actuation response trades lift against balance.** With a 1 Hz response
   pole the foot almost never clears 15 mm (94 %) and the robot almost never
   falls; at 3 Hz it lifts (33 % no_lift) and falls 36 %. The measured servo
   (2 Hz + 80 ms) sits between: the open-loop walk has no setting that does
   both, which is the policy's job.
4. **Short swings fail both ways** (more falls and less lift): keep swings
   ≥ 1.2–1.6 s for the kinematic walk.
5. **Higher friction falls more** (17.5 → 31.1 %), most likely the swing foot
   catching at low clearance; unconfirmed, to check with the fall times and
   foot traces.
6. **Backward slopes are worse than forward ones** (30.7 vs 21.7 % falls):
   the heel margin is small.
7. **Servo strength and stiffness inside the bench's band hardly matter** to
   the open-loop walk; play, backlash and lag dominate.

Data: `sim/runs/failure_sweep/20261006_laptop/`,
`sim/runs/failure_sweep/20261007_laptop_realistic/` and Mira's
`sim/runs/failure_sweep/20261006_mira/` (results.csv, summary.md; gitignored,
regenerate with the commands in `sim/failure_sweep.py`).

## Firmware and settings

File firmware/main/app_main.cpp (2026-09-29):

// Boot: bring up the hardware, create the three tasks, then get out of the way.
//
// Everything that will ever be allocated is allocated here, before any task
// runs (firmware-design section 2: no heap after init). The board comes up in
// bench mode with torque off -- a powered board must not move because nobody
// told it not to.
#include <string.h>

#include "board.h"
#include "cli.h"
#include "ctrl_task.h"
#include "imu_sampler.h"
#include "driver/uart.h"
#include "esp_log.h"
#include "esp_task_wdt.h"
#include "imu/imu.h"
#include "imu/qmi8658.h"
#include "link_task.h"
#include "nvs_flash.h"

#include "cal_store.h"
#include "policy/mlp.h"
#include "scs_port_idf.h"
#include "shared.h"
#include "wifi_link.h"

namespace robot {

// -- the shared state declared in shared.h ---------------------------------
std::atomic<Mode> g_mode_request{Mode::kBench};
std::atomic<bool> g_ctrl_owns_bus{false};
std::atomic<uint32_t> g_link_arm_edges{0};
std::atomic<uint32_t> g_link_home_edges{0};
std::atomic<bool> g_link_arm_level{false};
std::atomic<uint8_t> g_arm_result{
    static_cast<uint8_t>(linkproto::ArmResult::kNone)};
std::atomic<float> g_shape_hz{obs::kShaperPoleHz};
std::atomic<uint32_t> g_obs_freeze{0};
std::atomic<float> g_obs_gyro_gain{1.0f};
QueueHandle_t g_cmd_mailbox = nullptr;
TelemetrySnapshot g_telemetry;
ObsDump g_obs_dump;
JointPose g_joint_pose;
scsbus::Bus* g_bus = nullptr;

namespace {
constexpr const char* kTag = "bimo";

// Statically constructed, never freed.
IdfPort g_port(board::kServoUart, board::kServoTx, board::kServoRx,
               board::kServoBaud);
scsbus::Bus g_bus_obj(g_port);

// The real part is the QMI8658C on the board itself. The stub stays as the
// fallback and is not vestigial: if the IMU does not answer -- unpopulated
// bus, a wiring fault, a board revision that moved it -- the loop still runs
// end to end reporting level and still, which is exactly what bench work
// needs. What must NOT happen is a robot that boots believing a dead sensor,
// so which one is live is logged at boot and reported by `stat`.
imu::Qmi8658Imu g_qmi(imu::Qmi8658Imu::Config{
    board::kI2cSda, board::kI2cScl, static_cast<uint32_t>(board::kI2cHz),
    board::kImuAddr, true, 8, 1024});
imu::StubImu g_stub;
imu::Imu* g_imu = nullptr;

}  // namespace

// `imu reinit` (cli.cpp): recover + re-init the QMI at runtime. The sampler
// task and ctrl hold g_imu; if we booted on the stub, swap the pointer once
// the real sensor answers (the sampler dereferences it every 4 ms, so the
// swap is a single aligned pointer store).
// Bias, mount and per-axis gyro scale from NVS onto the live QMI. Called at
// boot when the part answered, and again from imuReinitLive(): a boot that
// fell back to the stub never applied them, and a later `imu reinit` used
// to bring the sensor back UNCALIBRATED (2026-09-03: bias 0, mount identity,
// 27 deg/s of raw x offset straight into the filter) with nothing but the
// `imu` status line to say so.
void applyImuCalFromNvs() {
    float bias[3] = {0.0f, 0.0f, 0.0f};
    float mount[4] = {1.0f, 0.0f, 0.0f, 0.0f};
    {
        float gs[3];
        if (imuGyroScaleLoad(gs)) g_qmi.setGyroScale(gs);
    }
    g_imu_cal_from_nvs = imuCalLoad(bias, mount);
    if (g_imu_cal_from_nvs) {
        g_qmi.setBias(bias);
        imu::Mount m;
        m.w = mount[0]; m.x = mount[1]; m.y = mount[2]; m.z = mount[3];
        g_qmi.setMount(m);
    }
}

bool imuReinitLive() {
    const bool ok = g_qmi.reinit();
    if (ok) {
        g_imu = &g_qmi;
        imuSamplerSetSource(g_qmi);
        applyImuCalFromNvs();
    }
    return ok;
}

bool g_imu_cal_from_nvs = false;


// Exposed for the bring-up CLI; null while the loop is on the stub.
imu::Qmi8658Imu* onboardImu() {
    return (g_imu == static_cast<imu::Imu*>(&g_qmi)) ? &g_qmi : nullptr;
}

namespace {

bool initHostUart() {
    uart_config_t cfg = {};
    cfg.baud_rate = board::kHostBaud;
    cfg.data_bits = UART_DATA_8_BITS;
    cfg.parity = UART_PARITY_DISABLE;
    cfg.stop_bits = UART_STOP_BITS_1;
    cfg.flow_ctrl = UART_HW_FLOWCTRL_DISABLE;
    cfg.source_clk = UART_SCLK_DEFAULT;
    if (uart_param_config(board::kHostUart, &cfg) != ESP_OK) return false;
    return uart_driver_install(board::kHostUart, 512, 512, 0, nullptr, 0) ==
           ESP_OK;
}

}  // namespace
}  // namespace robot

extern "C" void app_main(void) {
    using namespace robot;

    esp_err_t err = nvs_flash_init();
    if (err == ESP_ERR_NVS_NO_FREE_PAGES ||
        err == ESP_ERR_NVS_NEW_VERSION_FOUND) {
        nvs_flash_erase();
        nvs_flash_init();
    }

    if (!initHostUart()) {
        ESP_LOGE(kTag, "UART0 init failed");
        return;
    }
    // The tether carries binary link frames as well as CLI text, and IDF's
    // logger writes to the same UART. Keep logs for the boot sequence, then
    // silence them so nothing interleaves with a telemetry frame.
    if (!g_port.begin()) {
        ESP_LOGE(kTag, "servo UART1 init failed");
        return;
    }
    g_bus = &g_bus_obj;

    const bool imu_ok = g_qmi.init();
    g_imu = imu_ok ? static_cast<imu::Imu*>(&g_qmi)
                   : static_cast<imu::Imu*>(&g_stub);
    if (!imu_ok) g_stub.init();

    // Gyro bias and the mounting rotation, both from NVS. Neither has a safe
    // default: an uncalibrated bias parks the attitude estimate tens of
    // degrees off (see cal_store.h), and an identity mount is only right if
    // the board happens to lie flat, which on this robot it does not. So a
    // missing blob is REPORTED, not papered over -- `imu` shows it too.
    if (imu_ok) applyImuCalFromNvs();

    // Restore servo calibration before anything can command a position. A
    // missing blob is the normal first-boot path -- defaults (zero 2048,
    // dir +1) are what a freshly "Set Middle Position"-ed servo gives you --
    // but `cal` reports which of the two you are running on, because the
    // difference is invisible until a leg moves the wrong way.
    g_cal_from_nvs = calLoad(calibration());
    const char* cal_how = g_cal_from_nvs ? "restored from NVS" : "DEFAULTS";
    if (!g_cal_from_nvs && calMigrateV2(calibration())) {
        // v2 -> v3, automatically and exactly: a v2 blob proves its servo
        // map, so each servo's zero and direction land on its bus joint,
        // IDs 1-10 fitted and 11-17 absent (cal_store.h). Re-saved as v3.
        g_cal_from_nvs = true;
        cal_how = "migrated v2 -> v3 (IDs 1-10 fitted)";
    }
    if (!g_cal_from_nvs && calMigrateV1(calibration())) {
        // v1 -> v3, automatically and safely: a v1 blob that exactly matches
        // the compiled as-built table (asbuilt_cal.h, the servo-map.md
        // measurement) IS that measurement, so it migrates without an
        // operator; anything else stays rejected and `run` refuses.
        g_cal_from_nvs = true;
        cal_how = "migrated v1 -> v3 (matched as-built table)";
    }

    // Bench mode, torque off: docs/wiring.md's bring-up order starts with a
    // released bus, and a board that wakes up holding a pose is a board that
    // cooks servos while you are still plugging things in.
    g_bus->torqueEnable(scsbus::kBroadcastId, false);

    // Plan B gain gate, boot half: registers 21/22 of every driven servo
    // against main/servo_gains.h. Reads only. A mismatch (or a servo that
    // does not answer -- e.g. the pack is not connected yet) is logged here
    // and put on the BENCH beacon; `run` re-reads before every arm.
    const bool gains_ok = cli::bootGainCheck([](const char* line) {
        char buf[160];
        size_t n = strlen(line);
        if (n >= sizeof buf) n = sizeof buf - 1;
        memcpy(buf, line, n);
        while (n > 0 && (buf[n - 1] == '\n' || buf[n - 1] == '\r')) --n;
        buf[n] = 0;
        ESP_LOGW(kTag, "%s", buf);
    });

    ESP_LOGI(kTag, "cal: %s, %d of %d bus servos fitted", cal_how,
             fittedBusJoints(calibration(), nullptr, nullptr),
             obs::kNumBusJoints);
    ESP_LOGI(kTag, "gains: %s", gains_ok ? "every servo at its expected P/D"
                                          : "NOT verified -- `run` will refuse "
                                            "until `gains` is clean");
    ESP_LOGI(kTag, "imu: %s, cal %s", g_imu->name(),
             g_imu_cal_from_nvs ? "from NVS" : "MISSING (run `imu bias`)");
    ESP_LOGI(kTag, "bus %d baud on GPIO %d/%d, %d joints, obs %d, policy %s",
             board::kServoBaud, static_cast<int>(board::kServoTx),
             static_cast<int>(board::kServoRx), obs::kNumJoints, obs::kObsDim,
             policy::kWeightsArePlaceholder ? "PLACEHOLDER" : obs::kRunName);
    startLinkTask();

    // After startLinkTask (the mailbox must exist), before the log silence
    // (so a driver-init failure is visible on the tether). Association and
    // DHCP finish asynchronously; `wifi` reports the result.
    {
        char ssid[33], psk[65];
        const bool creds = wifiCredsLoad(ssid, sizeof ssid, psk, sizeof psk);
        ESP_LOGI(kTag, "wifi: %s%s",
                 creds ? "joining " : "no credentials (`wifi <ssid> <psk>`)",
                 creds ? ssid : "");
    }
    startWifiLink();
    esp_log_level_set("*", ESP_LOG_NONE);

    startHousekeepingTask();
    startImuSampler(*g_imu);
    startCtrlTask(*g_imu);
}

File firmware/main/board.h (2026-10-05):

// Waveshare "General Driver for Robots" board map (rev 1.2).
//
// This REPLACES the "Servo Driver with ESP32" map that stood here until
// 2026-08-14. The two boards are not interchangeable and the differences are
// not cosmetic:
//
//   * The servo bus is the ONE thing that survives unchanged: UART1 at 1
//     Mbaud, GPIO 18 = RX and GPIO 19 = TX, half-duplex switched in hardware
//     off the TX line with no direction GPIO. That is why the firmware ran on
//     this board before any of the rest of this header was true -- the bus is
//     the only part of it the code actually drove.
//
//   * I2C moves from GPIO 21/22 to GPIO 32 (SDA) / 33 (SCL), and it is no
//     longer an empty bus. On-board: QMI8658C 6-axis IMU at 0x6B, AK09918C
//     magnetometer at 0x0C, BMP280 barometer at 0x77, INA219 power monitor at
//     0x42. Header P1 brings the same bus out; 0x4A/0x4B stay reserved for a
//     BNO085 on P1 (docs/sensor-expansion.md).
//
//   * There is NO OLED. The old board's SSD1306 at 0x3C does not exist here,
//     so the display constants are gone rather than wrong.
//
//   * There IS a battery-voltage sense. The old header stated flatly that
//     the board had no ADC and that pack voltage therefore had to come off
//     the servo bus at 0.1 V resolution; the INA219 at 0x42 makes that false.
//     battguard still reads the servo bus today -- switching it is a separate
//     job (the INA219 shunt sits between DC_IN and the buck's VIN, so it sees
//     pack voltage even with the servo bus released, which is strictly better
//     than register 62).
//
//   * The RGB LED moves from GPIO 23 to GPIO 4 (header H2, through a 10 R
//     series resistor).
//
//   * TWO USB-C ports, both CP2102N, and only ONE of them flashes anything.
//     The port silkscreened "USB" carries the ESP32 console with the
//     DTR/RTS auto-program circuit; the one silkscreened "LIDAR" is a
//     separate bridge to P_TX/P_RX for a host computer. Plugging into LIDAR
//     still enumerates a /dev/ttyUSB*, which is the trap -- it just never
//     syncs. Confirmed on the bench 2026-08-14: MAC xx:xx:xx:xx:xx:xx,
//     ESP32-D0WD-V3 rev 3.1.
//
// Sources: the vendor schematic (docs/datasheets/general-driver/
// General_Driver_for_Robots-schematic.pdf) and the connector/net map derived
// from it in docs/sensor-expansion.md section 1. Waveshare publishes no user
// manual for this board.
#pragma once
#include "driver/gpio.h"
#include "driver/uart.h"

namespace board {

// -- servo bus (UART1) -----------------------------------------------------
constexpr uart_port_t kServoUart = UART_NUM_1;
constexpr gpio_num_t kServoRx = GPIO_NUM_18;
constexpr gpio_num_t kServoTx = GPIO_NUM_19;
constexpr int kServoBaud = 1000000;
// No direction pin: the board switches the transceiver from the TX line.
constexpr gpio_num_t kServoDirection = GPIO_NUM_NC;

// -- host link / console (UART0 over the "USB" CP2102N) --------------------
constexpr uart_port_t kHostUart = UART_NUM_0;
constexpr int kHostBaud = 115200;

// -- I2C -------------------------------------------------------------------
constexpr gpio_num_t kI2cSda = GPIO_NUM_32;
constexpr gpio_num_t kI2cScl = GPIO_NUM_33;
// 400 kHz is the parts' ceiling, but the QMI8658C sits behind an LSF0204PWR
// level shifter whose rise time is set by the bus pull-ups; if the bench scan
// is flaky at 400 k, drop to 100 k before suspecting the driver.
constexpr int kI2cHz = 400000;

constexpr uint8_t kImuAddr = 0x6B;           // QMI8658C (SA0 high)
constexpr uint8_t kImuAddrAlt = 0x6A;        // QMI8658C (SA0 low)
constexpr uint8_t kMagAddr = 0x0C;           // AK09918C -- unused, see below
constexpr uint8_t kBaroAddr = 0x77;          // BMP280 -- unused
constexpr uint8_t kPowerAddr = 0x42;         // INA219 -- unused (battguard TODO)

// The magnetometer is deliberately NOT used. The obs frame needs an up-vector
// and body rates, never a heading, and a magnetometer bolted to the same PCB
// as eight ST3215s drawing ~10 A transient measures those servos, not north.
// It stays on the bus and stays unread.

// -- misc ------------------------------------------------------------------
constexpr gpio_num_t kRgbLed = GPIO_NUM_4;   // H2, WS2812 through 10 R
constexpr gpio_num_t kBootButton = GPIO_NUM_0;
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

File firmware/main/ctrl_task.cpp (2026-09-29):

// The 50 Hz control loop (firmware-design section 1), pinned to core 1.
//
// Nothing here allocates, blocks on core 0, or takes a lock. The task blocks
// on a direct-to-task notification from a hardware esp_timer, so the wake
// jitter is microseconds rather than scheduler ticks.
#include "ctrl_task.h"

#include <math.h>
#include <string.h>

#include "battguard/guard.h"
#include "esp_attr.h"
#include "esp_task_wdt.h"
#include "esp_timer.h"
#include "freertos/FreeRTOS.h"
#include "freertos/task.h"
#include "imu_sampler.h"
#include "linkproto/watchdog.h"
#include "mech_envelope.h"
#include "obs/actuation.h"
#include "obs/assembler.h"
#include "policy/mlp.h"
#include "shared.h"

namespace robot {
namespace {

constexpr int kTickUs = 20000;                 // 20 ms == obs::kControlDt
constexpr uint32_t kOverrunUs = 2 * kTickUs;   // trips torque release

// Statically allocated task (firmware-design section 4: no dynamic task
// creation after init).
constexpr int kStackWords = 6144;
StackType_t g_stack[kStackWords];
StaticTask_t g_tcb;
TaskHandle_t g_task = nullptr;
esp_timer_handle_t g_tick_timer = nullptr;

// Loop-owned state. Single writer, never shared.
imu::Imu* g_imu = nullptr;
linkproto::Watchdog g_dog;
// Outlives g_dog across bench/run handovers -- it has to see the ARM edge
// that ENDS a run (linkproto/watchdog.h).
linkproto::ArmLatch g_arm;
// The "reset the servos" request. Fed in both modes, exactly like g_arm --
// its whole point is to work while benched, fallen or E-stopped.
linkproto::HomeLatch g_home;
battguard::Guard g_batt;
obs::Calibration g_cal;
obs::History g_hist;
obs::GaitClock g_clock(1.5f);
obs::VelocityEstimator g_vel;

float g_prev_action[obs::kActDim];
float g_frame[obs::kFrameDim];
float g_obs[obs::kObsDim];
float g_action[obs::kActDim];
float g_q[obs::kNumJoints];
float g_dq[obs::kNumJoints];
int32_t g_target_steps[obs::kNumJoints];
uint16_t g_target_speed[obs::kNumJoints];

// C2 command shaping (obs/actuation.h): the policy's raw 50 Hz targets go
// through three cascaded lags so the trajectory the servos chase has
// continuous velocity and acceleration, and each SYNC WRITE carries the speed
// that reaches the shaped target by the next tick -- instead of the max-speed
// slam-and-wait that put a 50 Hz velocity square wave on every joint.
// prev_action stays the RAW policy output: that is what the policy saw in
// training; the shaper is downstream of the policy's world.
obs::CommandShaper g_shaper;
static_assert(obs::kGoalSpeedMax == scsbus::kMaxGoalSpeed,
              "obs's speed ceiling must match the servo's");
// The BUS side (obs/bus_map.h). The loop reads and writes every FITTED bus
// joint (Calibration::fitted), not just the policy's: the policy's joints
// get the policy's targets, and every other fitted servo -- the robot's
// ankle rolls, neck and arms under a 10-joint policy -- is HELD where it was
// measured at takeover. Unfitted servos (IDs 11-17 on the prototype) are not
// on the wire at all: a SYNC READ that waits on an absent servo costs its
// whole timeout every tick. The fitted list is taken from the calibration
// at the arm handover, when the CLI cannot be changing it.
scsbus::Feedback g_fb[obs::kNumBusJoints];   // bus-indexed, last reply kept
bool g_fb_ok[obs::kNumBusJoints];            // answered THIS tick
float g_qbus[obs::kNumBusJoints];            // measured, rad; 0 if never read
int g_nfit = 0;
int g_fit_bus[obs::kNumBusJoints];           // fitted slot -> bus index
int g_fit_pol[obs::kNumBusJoints];           // fitted slot -> policy index, -1
uint8_t g_fit_id[obs::kNumBusJoints];        // fitted slot -> servo ID
scsbus::Feedback g_fit_fb[obs::kNumBusJoints];
bool g_fit_ok[obs::kNumBusJoints];
// The hold of a fitted servo the policy does not drive: its measured ticks at
// the first acting tick after an arm (or the first tick it answers). A servo
// the deployed run holds at a trained target (obs_spec.h kHeld*) ramps from
// there to that target; any other stays where it was measured.
int32_t g_hold_steps[obs::kNumBusJoints];
bool g_hold_valid[obs::kNumBusJoints];
// One SYNC WRITE's worth, in fitted-slot order.
uint8_t g_wr_id[obs::kNumBusJoints];
int32_t g_wr_steps[obs::kNumBusJoints];
uint16_t g_wr_speed[obs::kNumBusJoints];
bool g_torque_on = false;
bool g_primed = false;

// Takeover ramp (issue #29, loop-owned). The tick the policy takes the bus
// after a bench->run handover it used to SNAP the joints from the bench's
// rigid zero hold straight to its own targets -- an actuation step training
// never produced, into a policy whose history ring holds nothing but its
// first frame. Two armed ground sessions fell within seconds of exactly that
// handover on 2026-08-31. So for the first kArmRampMs of ACTING ticks the
// written targets blend from the pose MEASURED at takeover toward the
// policy's shaped targets: target = mix(q_hold, shaped, r), r 0->1. The
// blend sits after the shaper and before angleToSteps, so the goal-speed
// streaming chases the blended trajectory; prev_action stays the RAW policy
// output, same rule as the shaper -- the ramp is downstream of the policy's
// world. Deliberately NOT mirrored in sil_lib.cpp: the SIL harness has no
// bench/run handover (sil_reset IS its episode start) and its column
// comparability must not move.
constexpr int kArmRampMs = 1000;
constexpr int kArmRampTicks =
    static_cast<int>(kArmRampMs / (obs::kControlDt * 1000.0f) + 0.5f);
float g_ramp_hold[obs::kNumJoints];   // measured pose at the takeover tick
int g_ramp_ticks = kArmRampTicks;     // >= kArmRampTicks == ramp done
bool g_ramp_held = false;             // g_ramp_hold captured yet?

// Fall latch (loop-owned). Thresholds and the rationale live in
// linkproto/protocol.h next to the kFallen state they produce.
constexpr int kFallDebounceTicks =
    static_cast<int>(linkproto::kFallDebounceMs / (obs::kControlDt * 1000.0f));
bool g_fallen = false;
int g_fall_streak = 0;

// Rolling late-tick statistics for telemetry.
uint32_t g_ticks = 0, g_late = 0;

void IRAM_ATTR onTick(void*) {
    BaseType_t woke = pdFALSE;
    vTaskNotifyGiveFromISR(g_task, &woke);
    if (woke) portYIELD_FROM_ISR();
}

// Release every servo in one broadcast frame. This is the failsafe path, so it
// must be the cheapest thing in the file.
void releaseAll() {
    if (g_bus) g_bus->torqueEnable(scsbus::kBroadcastId, false);
    g_torque_on = false;
}

void engageAll() {
    if (g_bus) g_bus->torqueEnable(scsbus::kBroadcastId, true);
    g_torque_on = true;
}

uint32_t fittedMask() {
    uint32_t m = 0;
    for (int k = 0; k < g_nfit; ++k) m |= 1u << g_fit_bus[k];
    return m;
}
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

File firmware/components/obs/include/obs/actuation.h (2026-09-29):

// Action <-> joint angle <-> servo ticks.
//
// Three coordinate systems meet here and mixing them up is the classic
// deploy-day failure:
//   action   [-1, 1] per joint, what the policy emits
//   angle    radians in the SIM's sign convention, what the MJCF joints use
//   steps    0..4095 encoder ticks in the SERVO's own frame
//
// The action -> angle map must match walker_env._action_to_ctrl() for the
// deployed run's action_map (loco_v5t: "full" -- piecewise-linear, action 0 ==
// the standing pose, full travel on each side). The angle -> steps map is
// per-servo calibration (docs/wiring.md bring-up step 4: "Set Middle Position"
// at the CAD-neutral pose), which is why it takes a Calibration rather than
// being baked in.
#pragma once
#include <stdint.h>

#include "obs/bus_map.h"
#include "obs/obs_spec.h"

namespace obs {

// Per-servo calibration, restored from NVS at boot, indexed by BUS joint
// (obs/bus_map.h: index b is servo ID b + 1), so it covers every servo the
// robot carries, not just the ones the policy drives. Defaults are what a
// freshly "Set Middle Position"-ed, correctly-oriented servo gives you.
//
// `fitted` says which bus joints this robot actually has: the 10-joint
// prototype carries IDs 1-10 and not 11-17. The control loop and the bench
// commands read and write fitted servos only -- a SYNC READ that waits on a
// servo which is not there costs its whole timeout every tick. `cal` sets it
// (a joint that answers `cal zero` is fitted; `cal fit` sets it by hand).
struct Calibration {
    int32_t zero_steps[kNumBusJoints];   // encoder value at joint angle 0
    int8_t dir[kNumBusJoints];           // +1 or -1: servo CW vs. joint positive
    uint8_t fitted[kNumBusJoints];       // 1 = this servo is on the robot
    Calibration() {
        for (int b = 0; b < kNumBusJoints; ++b) {
            zero_steps[b] = 2048;     // scsbus::kCenterSteps
            dir[b] = 1;
            fitted[b] = 1;            // expect every servo until told otherwise
        }
    }
};

// walker_env._action_to_ctrl(), action_map == "full":
//   span = action >= 0 ? (hi - default) : (default - lo)
//   angle = default + span * clamp(action, -1, 1)
void actionToAngles(const float* action, float* angle_rad);

// Inverse, used to seed prev_action after a torque re-engage so the policy is
// not handed a discontinuity.
void anglesToAction(const float* angle_rad, float* action);

// Angle <-> encoder ticks, 4096 ticks per revolution, for POLICY joint j
// (obs_spec order): the calibration row is policyToBus(j)'s. angleToSteps
// clamps to the policy range kJointLo/Hi first -- that clamp is SIL-pinned.
int32_t angleToSteps(int joint, float rad, const Calibration& cal);
float stepsToAngle(int joint, int32_t steps, const Calibration& cal);

// The same maps for BUS joint b, without any joint-range clamp: bounded only
// by the encoder's 0..4095. For callers that clamp against a DIFFERENT range
// first (the CLI bench clamps to the measured mechanical envelope,
// main/mech_envelope.h) or that report where a joint is.
int32_t busAngleToStepsRaw(int bus, float rad, const Calibration& cal);
float busStepsToAngle(int bus, int32_t steps, const Calibration& cal);

// The servo reports speed in steps/s (register 58). Whether the policy is fed
// this or a finite difference of positions is an open sys-ID question
// (docs/firmware-design.md section 8) -- the sim uses true qvel and ToddlerBot
// finite-differences. Both paths are provided; the control task picks one.
// Policy joint j, like angleToSteps.
float stepsPerSecToRadPerSec(int joint, int32_t steps_per_s,
                             const Calibration& cal);

// -- command shaping ---------------------------------------------------
// The policy emits a new position target every 20 ms; written raw (speed 0 ==
// unlimited) the servo slams at max speed to each one, arrives mid-tick and
// stops dead -- a 50 Hz velocity square wave on every joint. The shaper turns
// that staircase into a C2 trajectory: three cascaded first-order lags, all
// poles at pole_hz. Each stage adds one derivative of smoothness, so the
// trajectory the servos are asked to follow has continuous velocity AND
// acceleration (finite jerk). Each stage is the exact zero-order-hold
// discretization, so it is stable for any pole/dt; all poles are real, so a
// step never overshoots; and the output never leaves the hull of its inputs,
// so a shaped target cannot exceed a joint's range if the raw ones don't.
//
// Default pole: 10 Hz, picked by closed-loop referee sweep (2026-08-02,
// loco_v8foot, 8 seeds/scenario through the SIL stack): stand_10s 8/8 and
// line_1m 8/8 at every pole tried; goal_home python 7/8 vs SIL raw 5/8,
// 16 Hz 7/8, 12 Hz 6/8, 10 Hz 6/8, 8 Hz 4/8. So 10 Hz is the strongest
// smoothing that stays inside the referee's parity budget -- 8 Hz measurably
// costs the policy task performance. Runtime-tunable (CLI `shape`); 0 means
// shaping off (the legacy raw path).
inline constexpr float kShaperPoleHz = 10.0f;

class CommandShaper {
  public:
    explicit CommandShaper(float pole_hz = kShaperPoleHz) {
        setPole(pole_hz, kControlDt);
    }
    // Recompute the per-stage gain: k = 1 - exp(-2*pi*pole_hz*dt).
    void setPole(float pole_hz, float dt);
    float poleHz() const { return pole_hz_; }
    // Seed every stage. Callers seed from MEASURED joint angles on a torque
    // (re)engage so the first shaped target can never be a jump.
    void reset(const float* angle_rad);
    // Forget the seed; the next update() self-seeds from its target. Called
    // when torque is released or the bus is handed away, so a re-engage
    // reseeds from wherever the joints actually are by then.
    void invalidate() { primed_ = false; }
    bool primed() const { return primed_; }
    // One control tick: raw targets in, shaped targets out (in-place safe).
    void update(const float* target_rad, float* out_rad);

  private:
    float y1_[kNumJoints] = {};
    float y2_[kNumJoints] = {};
    float y3_[kNumJoints] = {};
    float k_ = 1.0f;
    float pole_hz_ = 0.0f;
    bool primed_ = false;
};

// The goal speed (register 46, steps/s) written alongside a shaped target:
// enough to close the gap from the MEASURED position to the target within one
// tick, with headroom. While tracking, that is the trajectory's own speed --
// no max-speed slam -- and under a disturbance the error term grows it back
// toward the old slam behaviour, so smoothing never costs stiffness. The
// floor keeps the field nonzero (0 means UNLIMITED to the servo); the ceiling
// is the servo's own kMaxGoalSpeed (static_asserted where scsbus is visible).
inline constexpr float kGoalSpeedHeadroom = 1.25f;
inline constexpr int32_t kGoalSpeedFloor = 50;     // steps/s
inline constexpr int32_t kGoalSpeedMax = 3400;     // == scsbus::kMaxGoalSpeed
uint16_t goalSpeedSteps(int32_t goal_steps, int32_t present_steps);
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

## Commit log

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2026-07-11 Walking policy, uneven-terrain RL, printable CAD part set, and project docs
    Simulation/RL (sim/):
    - walker_env.py: Gymnasium env with reward shaping, domain randomization,
    gait-quality terms (feet air-time, single support, lateral/yaw), and
    per-episode procedural heightfield terrain with local-ground termination
    - train_ppo.py / eval_policy.py / compare_runs.py: SB3 PPO training,
    evaluation, and run-ranking tooling; build_report.py renders the visual
    training log (sim/runs/night_summary.html, committed)
    - Recommended policy terrain_v4: 0.79 m/s clean stride, survives 15 mm
    rough ground and +/-15% mass / +/-40% friction / +/-20% gain model error
    Printable CAD (cad/):
    - build123d pa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
    [assembly.step, foot.step, foot.stl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]
2026-07-11 GoPro MAX mount + fly-in assembly animation
    - New gopro_base part: standard 3-prong GoPro mount (GoProScad dims,
    3.2 mm slots) as a bolt-on crash fuse atop the tower; camera lens
    axis fore-aft. 7 unique parts / 13 prints, all bed-checked.
    - Tower rework: driver board relocated inside on standoffs (cleaner
    top, lower CG), thicker feet tabs + gussets for the 154 g camera
    cantilever. Mass rollup: 889 g bare -> 1043 g with camera, CG +29 mm.
    - animate_assembly.py: fly-in animation along real insertion paths
    (renders/assembly_flyin.gif) to verify parts can physically come
    together; enumerates parts from export_assembly so it tracks the
    part set. Assembly render/exports updated with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
    [assembly.step, foot.step, gopro_base.step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]
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2026-07-12 Reconcile sourced BOM with sim-validated specs; add wiring diagram
    Three order-critical corrections to docs/bom-sourced.md:
    - Servos: the $16.99 7.4V ST3215 class is rated 4-7.4V only and would
    foreclose the sim-recommended 3S battery; buy the 12V class (6-12.6V).
    - Driver: sourced Bus Servo Driver HAT (A) is a Pi HAT (65x57, 9-25V in,
    can't run 2S); correct board is Servo Driver with ESP32 (65x30,
    6-12.6V, 2S and 3S direct per Waveshare docs).
    - Battery: JST-terminated packs (~3A) undersized for 8 servos; want XT30.
    Plus: BOARD_HOLES corrected to the published 58x23 grid (was a 58x24
    guess) with regenerated assembly render/STEP/fly-in, gaps noted
    (charger, spares, switch, extensions)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
    [assembly.step]
2026-07-12 3S decided: swap-window battery bay, pin-level circuit diagram
    Battery decision executed (3S 11.1V, Zeee 850mAh 100C XT30 2-pack):
    - Tower reworked for tool-free swaps: the old design needed the tower
    unscrewed to reach the pack (feet tabs block end-insertion). Now the
    pack tilt-loads through a window in the -x wall over a 2.5mm sill,
    seats on far-wall rail stubs between the feet-tab gussets, and a
    20mm hook-loop belt in guide ribs closes the window; ribbon pull-tab
    for extraction. TOWER_H 32->37, BATT parametric on the real pack.
    - Fly-in animation now proves the swap path: battery stage waits for
    the tower to land and the camera swings to the window side; per-stage
    delays add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
    [assembly.step, tower.stl]
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2026-07-15 gopro_base: teardrop the M5 clamp bore (fixes weak bridged hole top) (#16)
    The M5 thumbscrew bore is horizontal in the print orientation (base down,
    prongs up), so its top arc printed as an unsupported bridge -- sagging,
    poorly-bonded strands exactly where the clamp squeezes across the layer
    lines. Reported symptom: weak across the top of the hole.
    Add teardrop_y(): the bore gets a 45deg self-supporting roof peak (apex at
    r*sqrt(2) above center, walls never exceed 45deg) so no layer overhangs the
    bridge. The M5 is a clearance fit, so the added void above the bolt is
    harmless; the round screw seat below is unchanged. Peak apex at z=17.4mm
    stays buried inside the Ø15 prong (top 21.0mm) -- wa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
    [gopro_base.step, gopro_base.stl]
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2026-07-15 foot v2: flat sole (kill underside bridge) + reinforced heel tabs (#18)
    First PETG foot print sagged badly on the underside: the TPU-pad recess
    bridged a 46 mm span printed sole-down. And a heel retention tab snapped in
    handling (thin 2.4 x 26 mm cantilever, weak interlayer).
    - Flat sole: drop the pad recess; glue a thin self-adhesive rubber pad on the
    flat underside (trim to fit). Ankle height unchanged (thin pad == old proud).
    - Reinforce tabs: lengthen aft (heel +4 mm, foot 96 -> 100 mm) with a 45 deg
    aft base buttress. Fore stays at -26 -- the shin fork sweeps forward of that
    (check_assembly caught a -18 extension colliding at ankle -40).
    - New wedge_y() helper for the gusset; che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
    [foot.step, foot.stl]
2026-07-15 Foot v3 (heel bulkhead) + printability gate; fix pelvis/tower/leg_link sag traps
    Foot v2's aft-gusseted tabs were still lone 2.4mm blades -- the snap mode was
    lateral, across layer lines. v3 ties both tabs into a heel bulkhead (U-channel,
    open-top cable window) with one full-width buttress; all added faces vertical.
    New cad/check_printability.py audits every STL in its PRINT orientation
    (bridges / >45deg overhangs / floating starts / first-layer contact) and gates
    like check_assembly.py. It caught three would-have-failed prints:
    - pelvis: stood on its 4 tower bosses, whole first layer 2mm in the air
    (bosses also overlapped the tower feet tabs) -> bosses deleted, heat-set
    pilots into dec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
    [assembly.step, foot.step, foot.stl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]
2026-07-15 foot: open the cable window for real (boolean-order bug) + THIN wall audit
    User caught a single-filament wall standing inside the v3 cable window: the
    full-width buttress was unioned AFTER the window cut, re-filling the window
    band with a wedge tapering to zero thickness. Cut the window last, clear
    through the heel edge.
    check_printability grows a THIN check: inward ray per facet measures local
    wall thickness, flags blades < 0.85mm (under two perimeters) whose exit face
    is near-parallel -- 45deg chamfer/gusset tips exit through angled faces and
    are exempt (the tower sill false-flagged until that filter). Verified the
    check catches the bad foot; full part set now ALL PARTS PRINT CLEAN and
    ch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
    [foot.step, foot.stl]
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2026-07-15 Teardrops: cap the roof at the round-hole envelope (no pierces/slivers)
    User caught full teardrop roofs (r*sqrt(2) reach) piercing edges and leaving
    paper shells where holes had round-hole margins: leg_link +10.25 case screws
    through the grip-plate edge (12.65 vs 12.36), peak-side BCD hole 0.1mm from
    every O19 idler boss OD. Roofs now truncate at center+r (1.4mm flat
    mini-bridge), so the void can never exceed the round hole it replaced;
    full=True only for proven-clear spots (gopro_base M5, byte-stable).
    Probed all flagged shells 100% solid; check_printability ALL PARTS PRINT
    CLEAN; check_assembly ALL CLEAR; STL/STEP/assembly artifacts + renders
    refreshed.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
    [assembly.step, foot.step, foot.stl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]
2026-07-15 Fix sub-perimeter hole-to-edge webs; THIN audit grid-samples large facets
    User caught webs down to a single filament between holes and edges:
    - leg_link +10.25 case screws ended 0.41mm from the grip-plate front edge
    (v1-era; screw heads also overhung) -> plates widened 12.36 -> 13.2,
    web now 1.25mm and heads fully seated
    - O14-BC bolt holes sat 0.8/0.3mm from the O9/O10 center reliefs on every
    joint pad -> reliefs shrunk to O8 (webs 1.3mm; ~1.1mm slack over the
    recessed O5.7 center screw -- verify on real horn/idler)
    THIN check now barycentric-grid-samples large facets instead of centroid
    only (webs beside holes live on big faces whose centroid is far away);
    flags all four webs pre-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
    [assembly.step, foot.step, leg_link.step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]
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2026-07-15 Hip -110/+60 (yoke_pitch idler-arm redesign) + soles 100->116 for get-up
    Get-up option (a) from DESIGN.md, executed:
    - The real hip limit was +/-105 deg: the thigh leg_link's idler grip
    plate/web share the idler yoke arm's Y band and sweep into its front
    edge. The idler arm is now a O28 hub + riser through the unswept
    top-rear sector, 45-deg print chamfer on the hub front (support-free
    flange-down). Clears -115/+65 with the FULL thigh assembly; horn arm
    unchanged.
    - check_assembly sweeps leg_link+servo (not just the servo) vs
    yoke_pitch across the range, plus deep-flexion vs yoke_roll/pelvis at
    roll 0/+-25. ALL CLEAR; printability gate clean.
    - Soles enlarged heel-biased (heel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
    [assembly.step, foot.step, foot.stl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]
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2026-07-15 Battery bay: fit the whole 3S 850 XT30 field, not one pack (#22)
    * Battery bay: fit the whole 3S 850 XT30 field, not one pack
    The bay was cut for the Zeee 3S 850 (67 x 30 x 18.5, 74 g), which is now
    unavailable on Amazon (direct-only, US stock out). That was a single-supplier
    dependency: the Zeee is long-and-flat at 18.5 mm, while every other 3S 850 is
    stubby-and-tall at 22-25 mm, so nothing was a drop-in. Height, not capacity,
    is the binding axis.
    Size the envelope to the field instead of one SKU:
    BATT 68 x 31 x 20 -> 68 x 31 x 26.5 (tallest pack 25 + 1.5 fit/pad)
    TOWER_H 37 -> 43.5 (= BATT[2] + 13.5 + 3.5 gap)
    Board-to-pack clearance is unchanged at 3.5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
    [assembly.step, foot.step, gopro_base.step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]
2026-07-16 leg_link v2: flush idler-side edge, fill dead horn-side slot (print review)
    User's annotated review of the first printed link flagged three things on
    the back web: the four holes (zip-tie cable anchors -- functional, kept),
    a 0.65 mm silhouette step on the idler side (web/grip plate ended at
    -20.35 while fork plate/jog sit at -21 -- now flush at -21), and the
    0.7 x 13.5 mm slot between web edge and horn fork plate (dead air: the
    chained-link grip-plate sweep that needs the 0.7 band tops out at z ~ -72,
    well below the slot -- now solid).
    Same x-z swing footprint, so every sweep clearance holds: check_assembly
    ALL CLEAR (incl. hip -115, knee x ankle combos), check_printability CLEAN.
    Point-in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
    [assembly.step, leg_link.step, leg_link.stl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]
2026-07-16 Pelvis bay walls: Ø22.5 -> Ø20.6 bore, restoring the 0.24 mm screw-hole web (#23) (#23)
    Print review caught it by eye in the slicer: on each bay wall the 8.30
    case-screw hole merged into the roll-axis U-slot.
    The screw row is fixed by the servo -- hypot(10.25, 8.30) = 13.19 from the
    axis -- so an Ø3.4 clearance hole reaches in to r 11.49. Against the Ø22.5
    bore (r 11.25) that leaves a 0.24 mm web: under one extrusion width, and the
    slicer merged the two voids into a sliver.
    Ø22.5 was carrying 1.45 mm of radial slack on a Ø19.6 case boss. leg_link
    already reliefs that same boss at r 10.3 (GRIP_HORN_RELIEF, 0.5 radial), so
    BAY_BORE is now SV_BOSS_D + 1.0 = Ø20.6 and the web is 1.19 mm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
    [pelvis.stl]
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2026-07-16 tower print revision: wedge gussets/stubs, 49-deg sill, tower_print.stl
    Slice review found the inverted tower still bridging: feet-tab gussets
    were flat-topped boxes (6 mm ceilings 31 mm over the interior), battery
    rail stubs stepped only 1.3 mm per ledge, and the window-sill ramp sat
    at 44 deg -- one degree past printable, painting the 70 mm band as
    overhang. Gussets and stubs are now true >=45 deg wedges, the sill ramp
    is 49 deg (full 2.5 mm outer lip kept), and feet screws seat on the
    tabs through 6.6 mm head wells. check_printability CEILING 13 -> 4
    (remaining are the counterbore roofs, <=8 mm standard bridges).
    New tower_print.stl (tower(print_supports=True)) adds four 1.6 mm
    break-awa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
    [tower.step, tower.stl, tower_print.stl]
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2026-07-16 tower: delete the window sill -- support-free print, belt is the retention
    The sill answered a slice-review escalation with a design question: the
    70 mm horizontal member printing 41 mm up in mid-air was the tower's
    only bridging problem (plain posts missed it -- its knife-edge underside
    drops ~1 mm of sub-nozzle layers; fan trees under a 1.2 mm flat lip band
    worked but added snap-out labor), and its only real job was parking the
    pack while the hook-loop belt -- the actual tumble retention -- was off.
    The window is now open to the deck; two 2.5 mm 45-deg corner detents
    off the window posts park the pack, self-supporting in the inverted
    print. tower_print.stl and the support trees are gone: s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
    [tower.step, tower.stl, tower_print.stl]
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2026-07-16 imu_carrier: screwed BNO055 mount between tower top and gopro_base
    Replaces the foam-tape IMU mount. The carrier clamps under the
    gopro_base on the same four tower bosses (screws M3x8 -> M3x12 for the
    3 mm plate) and cantilevers a tongue rearward with 4x M2.5 bosses on
    the breakout's true hole pattern. No tower change -- the printed tower
    stands.
    The ordered IMU (Amazon B0GVK81HXR) is the CLASSIC BNO055 breakout,
    not the BOM's BNO085/STEMMA pick: outline 26.67x20.32, holes
    21.59x15.24 (measured from Adafruit's Eagle .brd; STEMMA-variant swap
    noted in dimensions.py), solder header -> 4x F-F jumpers, I2C 0x28.
    Same on-chip fusion at 100 Hz -- control plan unchanged.
    Verified: stack zero-inte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
    [assembly.step, imu_carrier.step, imu_carrier.stl]
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2026-07-16 leg_link: solid slab backing -- break-aways reduced to one fin + 2 stubs
    Follow-up to the v3 fins (still judged trapped in slice review). The
    foot-sweep re-map at ankle +-45 shows the swept volume in the fork slab
    bands is only below z -93 (heel under the axis) plus the idler side up
    to -55.6 (wall corner at -45). Everything else now fills PERMANENTLY to
    the web face -- the feedback's own words, 'make it solid': the horn
    slab is a full-depth blade (z -92..-50), the idler side a stub above
    -54. leg_link_print.stl keeps just one short free-ended toothed fin
    (idler, -92..-56, no pad cradle hooking it) and two 4 mm finger-snap
    stubs under the pad tangents where the foot sweep forbids permanent
    m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
    [assembly.step, assembly_full.step, leg_link.step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]
2026-07-16 leg_link: NO fins -- solid fills + ribbon bridge + 2 island pad stubs
    Root cause of the 'unremovable breakaway' (user diagnosis, confirmed by
    first-layer island analysis of the sliced gcode): the fins' bed
    footprints overlapped the web's footprint, so layer 1 printed the
    breakaway and the back plate as one continuous sheet -- no break line
    existed, and every above-bed gap/tooth tweak was irrelevant.
    Fix: no fins at all.
    - Foot-sweep fine map: the idler corner lobe is exactly z -68.4..-55.6
    (ankle -33..-45), so the idler slab is ALSO solid-backed below it
    (z -92..-70) in addition to above (-54..-50). Horn side unchanged
    (full blade).
    - The 16 mm idler stretch between fills is anchored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
    [assembly.step, assembly_full.step, leg_link.step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]
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2026-07-23 hip-yaw CAD cut: redesigned pelvis + yaw_carrier x2 (v3yaw)
    Yaw-first stack per docs/hip-yaw-study.md: STS3215 flat under the deck
    per leg (horn down, deck = stator bracket), yaw_carrier bolts to the horn
    and carries the old roll bay verbatim (BAY_BORE/BAY_WALL_DROP/U-slot
    unchanged); roll servo, yokes, leg_link, shin, foot untouched.
    check_assembly ALL CLEAR incl. yaw 0/+-45 sweeps and both-carriers-inward
    (6.2 mm worst gap); check_printability clean, support-free, ORIENT map
    updated. True stack height 40.8 mm (servo grip span sets the floor; the
    28 mm study estimate was optimistic) -> structure top 330.5 -> 371 mm;
    sim v3yaw torso raise must be +41 mm. Mass: printed 307 -> 329 g; robot
    ~91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
    [pelvis.step, pelvis.stl, yaw_carrier.step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]
2026-07-23 v3yaw wiring chases + regenerated assembly artifacts + FreeCAD articulation
    User review caught wires passing through solid mounts: moving the roll
    bays off the pelvis deleted the old per-bay deck cutouts, leaving the
    board->yaw and yaw->roll leads no passage. Cut WIRE_CHASE_1 (12 mm rear
    deck chase between the stator screws) and WIRE_CHASE_2 (14 mm carrier
    rear channel, rounded corners, 1.55 mm ligament to the retention screws);
    printability + assembly checks green incl. full yaw sweeps; wiring render
    shows the harness through real openings (renders/hip_yaw_wiring.png).
    Regenerated against the fixed geometry: assembly.step + dressed
    assembly_full.step (v3yaw stack, structure top 372 mm), all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
    [assembly.step, assembly_full.step, bimo_v3yaw_articulated.FCStd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]
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2026-07-23 wiring audit rev-2: carrier connector clearance + fastener guide + reconciled BOM
    User review round 2 ('still might need cable holes in the pelvis?')
    triggered a full-assembly harness audit. Verdict: the pelvis chases exist
    (proven by solid sectioning) and the center window carries the board->yaw
    descent -- but the CARRIER's horn plate capped the roll servo's up-facing
    cable connectors (15-183 mm^3 interference, 3.1 mm gap). Fix: cable
    channel opened forward (YAW_CH_FRONT -6), rear-most horn bolt dropped --
    yaw horns take 3x M3x6 (Ø14 circle, ~0.3 N.m load OK). Checks green;
    deciding renders: hip_yaw_wiring.png + _front.png (full assembly,
    semi-transparent, red harness board->thigh threadin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
    [assembly.step, bimo_v3yaw_articulated.FCStd, yaw_carrier.step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]
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2026-07-23 design-review fixes round 3: idler through-holes, fork cable notch, foot divots
    Three user findings from the exploded drawings + FreeCAD review, all
    verified real and fixed in parts.py/dimensions.py:
    1. Idler bolt circle was a modeling bug from the original commit -- bores
    started at SV_IDLER_FACE-1 (the disc face) and never reached the outer
    plate on leg_link/yoke_pitch/yoke_roll; the bolted-idler intent is
    proven by the BOM's idler washers. Now through-drilled (user decision:
    hand-drill existing prints using the blind recesses as guides; future
    prints correct). IDLER_BOSS_D 19->20 for web thickness at the new
    holes. Load rationale on record: knee/ankle impact moments ~1-4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
    [assembly.step, bimo_v3yaw_articulated.FCStd, foot.step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]
2026-07-23 revert invented leg_link notch; ankle-cable sweep proves 10 mm clearance
    User challenged the rounded-square idler-fork cutout -- correctly. It was
    an artifact: the 171 mm^3 'interference' assumed a lead routed down the
    idler exterior, a path the design never uses (web window -> back raceway
    is the real route). Git pickaxe confirms no notch ever existed to
    resurrect. Cutout removed, constants deleted with a do-not-re-add note;
    fork plate solid again. The real concern (ankle lead vs shin fork at
    toes-pointed) analyzed properly: connector swept through full ankle ROM
    incl. an oversized heel block -- 0 mm^3 at all poses, ~10 mm min
    clearance (connector swings up-and-aft, away from the fork). Per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
    [assembly.step, bimo_v3yaw_articulated.FCStd, leg_link.step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]
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2026-07-24 exploded sheets: symbolic fastener glyphs (user: must read as screw/washer/disc)
    Hardware no longer goes through HLR (plain cylinders projected as
    unreadable ellipse stacks). Each fastener is drawn as a screen-space SVG
    symbol on its projected axis at fixed legible size: dome-head machine
    screws with thread ticks, pointed self-tappers with chevron threads,
    washers as foreshortened annuli, knurled heat-set inserts, spline screws,
    knurled thumbscrew; horn/idler discs stay real HLR (bolt circles identify
    them). Multi-screw patterns collapse to one representative glyph + NX,
    per the reference. Master resheeted 1440 sq with the item table as a
    bottom strip so the drawing dominates; 'FASTENERS ENL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
    [assembly.step]
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2026-07-24 yaw seat + connector openings from measured servo geometry (vendor STEP)
    User's photo showed the first-pass connector window was still wrong.
    Downloaded the Waveshare ST3215 STEP + 2D drawing and measured the idler
    face: the two sockets sit in a TRENCH 11.75..16.35 mm behind the axis
    (+-10.9 wide, 4.78 deep) opening out of the face; stator screw bosses are
    1.78 mm recessed; the idler disc + free-hub post (O6.1) sit at/proud of
    the slab plane. New SV_IDLER_*/SV_CONN_* constants replace the inferred
    band.
    - pelvis yaw seat is no longer a flat face: O21.5 pocket clears the
    ROTATING disc/post (clamping them would bind the yaw joint), 4x O7
    pads land on the recessed screw bosses, connector d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
    [assembly.step, assembly_full.step, bimo_v3yaw_articulated.FCStd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]
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2026-07-26 firmware v1: ESP-IDF skeleton, SCS/STS bus, protocol port, host tests green
    First firmware in the repo. Nothing flashed -- the board is on the bench under
    vendor firmware, and flashing stays a user-gated step. What is proven today:
    make -C firmware/host test -> 1866 checks, 0 failures (ASan+UBSan)
    - scsbus/: Feetech SCS/STS codec + transactions -- PING, READ/WRITE, REG WRITE
    + ACTION, SYNC READ/WRITE, torque enable/release incl. broadcast, EEPROM
    lock/unlock, ID change, set-middle, position correction, error decode.
    Golden packets are the worked examples from Feetech's own protocol manual.
    - linkproto/: byte-exact port of link/protocol.py (CRC 0x29B1, frames,
    clamp_to_envelope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
    [actuation.cpp, actuation.h, app_main.cpp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]
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2026-07-26 fix the 50 Hz loop: sync read was sleeping out its timeout, 29.9 ms -> 2.8 ms
    The first hardware run of the control loop missed its period badly: 32 ms
    ticks against 20 ms, every tick late -- but servo_err 0x0000, which none of
    the tick-budget lines explained. Added per-phase timing to stat rather than
    keep guessing, and it landed in one run:
    phases us: read 29916 imu 11 obs 31 net 881 write 71 other 75
    Bus::syncReadFeedback asked port_.read() for the whole remaining buffer, and
    uart_read_bytes() returns only when it has the requested count or the timeout
    expires. That request could never be satisfied, so every read slept out its
    full reply_timeout_us * n = 30 ms deadline -- while t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
    [bus.cpp, cli.cpp, ctrl_task.cpp]
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2026-07-26 calibration persists in NVS + `cal` CLI; friction measured at 0.235 N.m
    obs::Calibration always claimed it was "restored from NVS at boot" and never
    was: g_cal default-constructed to zero 2048 / dir +1 on every power-up, so a
    calibration made at the CAD-neutral pose survived until the next reset. That
    would have been discovered with the robot half-assembled.
    cal_store.{h,cpp} versioned CRC-32 blob in NVS. Rejects wrong magic,
    version, joint count (the 8->10 DOF change is exactly why
    that field exists), bad CRC, or out-of-range values --
    and leaves the destination untouched on every rejection,
    so a stale b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
    [actuation.cpp, app_main.cpp, cal_store.cpp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]
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2026-07-27 imu_carrier redesigned for the real GY-BNO08X: pocket-located, no screws
    The board on hand is not the one the old carrier was built for. The retired
    BNO055 breakout was 26.67 x 20.32 with FOUR holes on a 21.59 x 15.24
    rectangle; the GY-BNO08X (Amazon B0CL26J81F, photographed today) is
    25.4 x 15.5 x 0.8 with only TWO holes, both hard against the castellated edge.
    Chip family is BNO080/085, so SH-2 -- the firmware's imu/ already targets it
    and needs no change.
    The carrier now LOCATES ON THE OUTLINE and models no screw holes at all. The
    only photo available is at an angle, so hole positions read from it carry
    ~+/-1 mm, far worse than the ~0.3 mm a boss needs -- and a boss built from a
    bad numb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
    [assembly.step, imu_carrier.stl]
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
